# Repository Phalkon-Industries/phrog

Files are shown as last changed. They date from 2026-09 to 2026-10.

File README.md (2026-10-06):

# phrog
Super low cost spectrophotometric ph sensor

What is the purpose of the pHrog?

To be an educational kit that people can build themselves and use to learn how to make a spectrophotometric measurement.

It should be able to do basic spectrophotometric measuremtns and be able to get pH to +-0.1 units. That is the goal. 

It should be easy to build, and be repairable.

Still under early development

## Repository layout

| Folder | Contents |
|---|---|
| `phrog-mainboard/` | KiCad project, datasheets, and production outputs for the mainboard. |
| `enclosure/` | FreeCAD enclosure model. |
| `firmware/` | PlatformIO firmware for the nRF52840 Pro Micro (see `firmware/README.md`). |

## License

This project is licensed under the CERN Open Hardware Licence Version 2 - Strongly Reciprocal
(`CERN-OHL-S-2.0`). See [`LICENSE`](LICENSE) for the full text.

Source Location: https://github.com/Phalkon-Industries/phrog

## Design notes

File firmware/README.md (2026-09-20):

# phrog Firmware

PlatformIO project for the phrog pH instrument mainboard. The layout mirrors the Phoenix
firmware (`phoenix-instrument/platformio/PoenixV1-Firmware`); shared modules are copied
verbatim so they can be kept in sync.

## Hardware

- nRF52840 Pro Micro / nice!nano module (Adafruit nRF52 Arduino core, UF2 bootloader).
- NAU7802 24-bit I2C ADC for the photodiode signal.
- Thermistor divider read on the nRF52840 internal SAADC.
- Green and blue LEDs driven directly from GPIO.

Pin assignments: `docs/pin-map.md` and `include/device_setup.hpp`.

## Layout

| Path | Contents |
|---|---|
| `boards/`, `variants/` | Project-local nice!nano board definition and pin variant. |
| `include/device_setup.hpp`, `src/device_setup.cpp` | Pin map, board configs, bring-up sequence. |
| `src/main.cpp` | Production entry point (device setup + CLI). |
| `src/examples/mock_main.cpp` | Mock BLE application for phone-app development (ported). |
| `src/examples/led_blink_main.cpp` | Bench example that cycles the measurement LEDs every second. |
| `src/examples/adc_monitor_main.cpp` | Bench example: photodiode ADC codes, dark and lit, as a plain fixed-width table with a LOW/GOOD/HIGH verdict for trimpot tuning. |
| `src/examples/adc_monitor_ansi_colored_main.cpp` | The same monitor redrawn in place with a coloured verdict column, for terminals that render ANSI. |
| `lib/phoenix_common` | Shared `GUARD` macros and `PHX_*` return codes (ported verbatim). |
| `lib/ph_equations` | Spectrophotometric pH maths (ported verbatim). |
| `lib/phoenix_ble` | BLE server facade + Bluefruit backend (ported verbatim). |
| `lib/mocks` | Mock controller and BLE bridge (ported verbatim). |
| `lib/nau7802` | NAU7802 driver (implemented; internal LDO, DRDY-gated reads, offset calibration). |
| `lib/led_driver` | GPIO LED drive (implemented; NPN current sinks, active high). |
| `lib/light_readings` | Sweep helper (implemented; per-photodiode dark and lit codes, saturation flag, statistics ported from Phoenix). |
| `lib/thermistor_reader` | SAADC thermistor measurement (implemented; ratiometric divider, Steinhart-Hart from Phoenix). |
| `lib/cli` | Serial command interface (implemented: `b` baseline, `s` sample + pH, `c` live monitor, `v`, `help`). |
| `lib/phrog_settings` | Persistent per-unit settings in internal flash (implemented; LittleFS via InternalFS, versioned file, sweep count and thermistor offset). |
| `test/` | Unity suites; one per module. |
| `python/` | Host tooling: mock BLE tester and pytest suite (ported). |
| `docs/` | Style guide, TDD and git workflow, pin map. |

## Building

```powershell
pio run -e main            # production firmware
pio run -e mock_main       # mock BLE app
pio run -e led_blink -t upload   # flash the LED cycling bench example
pio run -e adc_monitor -t upload               # flash the plain photodiode ADC monitor (trimpot adjustment)
pio run -e adc_monitor_ansi_colored -t upload  # same monitor, redrawn in place with colour
pio device monitor -e adc_monitor_ansi_colored # watch it; the env passes the ANSI codes through
pio test -e main -vv       # full Unity suite on hardware
pio test -e main -vv -f *nau7802*
```

Run `pio` from this directory. See `docs/contributor-checklist.md` before starting work.

## Status

All planned modules are implemented and tested on hardware: LED drive, NAU7802 ADC, thermistor,
sweeps with statistics, the serial CLI, and flash-backed settings. BLE in the production app is
not yet wired up (the `mock_main` environment carries the ported Phoenix BLE stack).

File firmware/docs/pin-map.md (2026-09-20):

# phrog Pin Map

The phrog mainboard uses a no-name nRF52840 "Pro Micro" clone on the nice!nano footprint. Firmware
pin macros are defined in `include/device_setup.hpp`; the board variant in `variants/nice_nano/`
uses an identity map, so Arduino pin `N` is nRF GPIO `N` (`P1.13` is `32 + 13 = 45`).

Source of truth for the routing is the KiCad project in `phrog-mainboard/`. The table below was
checked against the PCB netlist.

## Header pins used by phrog

| Function | nRF pin | Arduino pin | Macro |
|---|---|---|---|
| Thermistor signal (SAADC)| P0.29 | 29 | `PIN_THERMISTOR_SIGNAL` |
| Thermistor drive | P0.02 | 2 | `PIN_THERMISTOR_DRIVE` |
| Green LED drive | P1.13 | 45 | `PIN_LED_GREEN_DRIVE` |
| Blue LED drive | P1.11 | 43 | `PIN_LED_BLUE_DRIVE` |
| NAU7802 DRDY | P1.00 | 32 | `PIN_NAU7802_DRDY` |
| I2C SCL (NAU7802) | P1.04 | 36 | `PIN_WIRE_SCL` (variant) |
| I2C SDA (NAU7802) | P1.06 | 38 | `PIN_WIRE_SDA` (variant) |

The thermistor divider is drive pin -> 10 k series resistor -> signal pin -> thermistor -> GND.
Each LED is an NPN current sink (10 k / 5.6 k base divider, 27 R emitter), GPIO active high.
The NAU7802 has blue on channel 1 (VIN1P) and green on channel 2 (VIN2P), both single-ended to
ground, with REFP tied to the internal LDO output.

## Module-internal pins

These are not on the header, and phrog does not currently use them. Their behaviour depends on
the board implementation, so `test/test_board_power` reports what it observes without failing
on the outcome. The values below are what our no-name clone did on the bench.

| Function | nRF pin | Arduino pin | Macro | Observed on our clone |
|---|---|---|---|---|
| Battery sense (SAADC) | P0.04 | 4 | `PIN_VBAT` (variant) | ~150 mV at the pin with no battery attached; divider ratio not yet confirmed. |
| Switched 3.3 V cutoff | P0.13 | 13 | `PIN_EXT_VCC_CUTOFF` (variant) | LOW switches off the module's 3.3 V output, which powers the NAU7802 and I2C pull-ups. HIGH or floating keeps it on. The nice!nano docs claim the opposite polarity. Leave it floating. |
| On-board LED (active low)| P0.15 | 15 | `LED_BUILTIN` (variant) | Blinks in `test_board_hello`. |

## Board definition

PlatformIO does not ship a nice!nano / Pro Micro board, so the project carries its own:

- `boards/nice_nano.json` — Adafruit nRF52 core, S140 v6.1.1 SoftDevice, Adafruit UF2 bootloader
  (same as the nice!nano ships with).
- `variants/nice_nano/variant.{h,cpp}` — pin map and peripheral defaults.

Both are selected from `platformio.ini` via `boards_dir`, `board = nice_nano`, and
`board_build.variants_dir`. The layout follows the community definition at
<https://github.com/ICantMakeThings/Nicenano-NRF52-Supermini-PlatformIO-Support>, kept inside
the repo instead of the global `.platformio` folder so every checkout builds the same way.

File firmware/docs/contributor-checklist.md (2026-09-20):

# phrog Firmware – Contributor Checklist

Use this checklist whenever you begin work in this repository. It captures the norms that keep firmware, host tooling, and documentation consistent.

## 1. Read the style guide
- Start with `docs/style-guide.md`. It covers naming rules (for example, store function return values in `return_code`), pointer usage, comment expectations, and formatting patterns specific to our Arduino targets.

## 2. Understand the project layout
- Firmware lives under `src/` and reusable drivers in `lib/`.
- Shared headers are in `include/`.
- Unity-based tests reside in `test/`.
- Host scripts and Python utilities live in `python/`.
- Pin mappings and board-wide constants are defined in `include/device_setup.hpp` (see `docs/pin-map.md`); reference them instead of adding literals.

## 3. Practice strict TDD
- Add or update Unity tests **before** changing behavior.
- Ensure tests fail first, then implement the fix or feature.
- Avoid removing tests unless the documented requirements change; adjust names or expectations as needed.
- When a plan is required, consult `docs/tdd-workflow.md` for the expected structure.

## 4. Use the PlatformIO flows
- Build the main firmware with `pio run -e main`.
- Run targeted Unity suites while iterating (`pio test -e main -vv -f <pattern>`).
- Run the full Unity suite (`pio test -e main -vv`) before shipping significant work.
- Always invoke `pio` commands from the repository root—avoid `cd ... && pio ...` wrappers that bypass automation.
- Run `clang-format` on every modified C++ source or header before committing.
- After firmware changes, compile the affected environments (for example, `pio run -e mock_main`) to prove they still build.

## 5. Test on real hardware
- Assume target boards are on your bench. Exercise new code on-device via PlatformIO.
- Do not introduce mocks or host-side simulators unless explicitly instructed.

## 6. Guard integrations
- Check existing modules in `include/` and `lib/` before adding new dependencies.
- Prefer extending the current drivers and helpers instead of introducing parallel implementations.

## 7. Explain the “why” in code
- Inline comments should justify non-obvious steps (for example, reset sequencing, timing delays, datasheet quirks).
- Update user-facing documentation or READMEs when visible behavior changes.

## 8. Commit cleanly
- Use merge-headline format `FW: <message>` when integrating to `main`.
- Keep topic-branch commits atomic and descriptive (see `docs/git-workflow.md` for details).
- Stage only related changes per commit and mention the validation you ran if it is not obvious.

## 9. Keep tests honest
- Never weaken or delete failing tests just to achieve a green run.
- Only modify test expectations when the documented requirements change, and explain why in your change notes.

## 10. Exercise the BLE regression suite
- Run the mock BLE workflows through pytest: `conda run -n phrog-python pytest python/tests/mock_ble/test_device_workflows.py --mock-ble -vv` so each command reports individually.
- Review `docs/mock_ble_testing.md` for option details, summary interpretation, and guidance on overriding the runner for simulation.

Keep this checklist alongside `docs/git-workflow.md`, `docs/style-guide.md`, and `docs/tdd-workflow.md` whenever you begin a new task. Together they cover process, style, testing discipline, and environment requirements.

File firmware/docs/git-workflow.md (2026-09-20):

# phrog Firmware – Git Workflow (Contributor Guide)

This document is the reference for how we manage topic branches, commits, and merges in the phrog firmware repo. Keep it handy when you start a new feature, bugfix, or refactor.

**Why we follow this workflow**

- Preserve small, atomic commits for traceability.
- Group related work behind descriptive merge commits created with `--no-ff` so the main branch tells a story.
- Stay focused by using lightweight topic branches instead of juggling parallel worktrees.
- Maintain an easy-to-scan history via `git log --first-parent` and merge boundaries.
- Align topic-branch commits with Conventional Commit structure while retaining the repository-standard `FW: …` headline for merges into `main`.

---

## Before you start a branch

1. Sync your main worktree:
   ```bash
   git fetch --all --prune
   git switch main
   git pull --ff-only
   ```
2. Decide on the branch scope and name using the patterns below.

## Branch naming

Create topic branches that reflect the type of work:

- `feat/<scope>-<short-summary>`
- `fix/<scope>-<short-summary>`
- `refactor/<scope>-<short-summary>`
- `chore/<scope>-<short-summary>`

Examples: `refactor/benchmark-timeouts`, `feat/channel-map-sweeps`.

> Keep branch names lowercase with dashes for readability. Avoid `wip/` prefixes—prefer starting a fresh branch when the direction changes.

---

## Commit messages inside the topic branch

Follow Conventional Commit headers so the history explains *what* changed without reading the diff:

```
<type>(<scope>): <imperative summary>
```

Types: `feat`, `fix`, `refactor`, `perf`, `docs`, `test`, `chore`, `build`, `ci`.

- ✅ `refactor(benchmark): isolate timing from IO`
- ❌ `update code`

Each commit should represent one logical change and include any tightly coupled tests or configuration updates.

> When you squash fixups locally, preserve the Conventional Commit header in the resulting commit.

---

## Start a topic branch

Create a branch directly in this workspace and keep all work for a change inside that branch.

1. Ensure `main` is up to date (see the previous section).
2. Create and switch to a branch in one step:
   ```bash
   git switch -c <topic-branch> main
   ```
   Example: `git switch -c fix/channel-map-timeouts main`
3. Develop on that branch, using `git add -p` for focused staging and keeping commits atomic.
4. When ready to share, push it with `git push -u origin <topic-branch>`.

---

## Keeping the branch current

- Periodically rebase onto `main` to absorb upstream fixes:
  ```bash
  git fetch --all --prune
  git rebase main
  ```
- Review the delta before merge:
  ```bash
  git range-diff origin/main...HEAD
  ```
- Run the full validation expected by the repository (see `docs/contributor-checklist.md` and `docs/tdd-workflow.md`).

---

## Merging back to `main`

1. Switch to the primary worktree and refresh `main`:
   ```bash
   git switch main
   git pull --ff-only
   ```
2. Merge with `--no-ff` so the topic branch remains visible:
   ```bash
   git merge --no-ff <topic-branch> \
     -m "FW: <concise summary of the grouped change>\n\n<bulleted summary / risks / scope>"
   ```
   - The merge commit message keeps the established `FW:` prefix while the body summarizes scope, rationale, and risks.
   - If you prefer Conventional Commit semantics, you can mention the type/scope in the body (for example, `Summary: feat(benchmark): expose timeout flags`).
3. Push `main` and any relevant tags:
   ```bash
   git push
   git push --tags # optional, when tagging a release
   ```

> Never fast-forward `main`. The merge commit is the “headline” for the grouped work.

---

## Branch lifecycle checklist

1. **Create** the topic branch with `git switch -c <topic> main`.
2. **Develop** with atomic Conventional Commit-style messages.
3. **Sync** regularly: `git fetch --all --prune && git rebase main` while on the topic branch.
4. **Self-review** with `git range-diff`, run required builds/tests, update docs.
5. **Merge** back to `main` using `git merge --no-ff <topic>` and an `FW:` merge headline.
6. **Tag** milestones when appropriate (for example, releases or major hardware validation).
7. **Delete** the topic branch after merge: `git branch -d <topic>` locally and `git push origin :<topic>` remotely.

---

## Quick reference

```bash
# Start a topic branch
git switch -c <topic> main

# Atomic commit loop
git add -p && git commit -m "refactor(benchmark): move timing helpers"

# Refresh against main
git fetch --all --prune && git rebase main

# Merge with grouped headline
git switch main && git pull --ff-only
git merge --no-ff <topic> -m "FW: consolidate benchmark timing\n\nSummary:\n- ...\n"

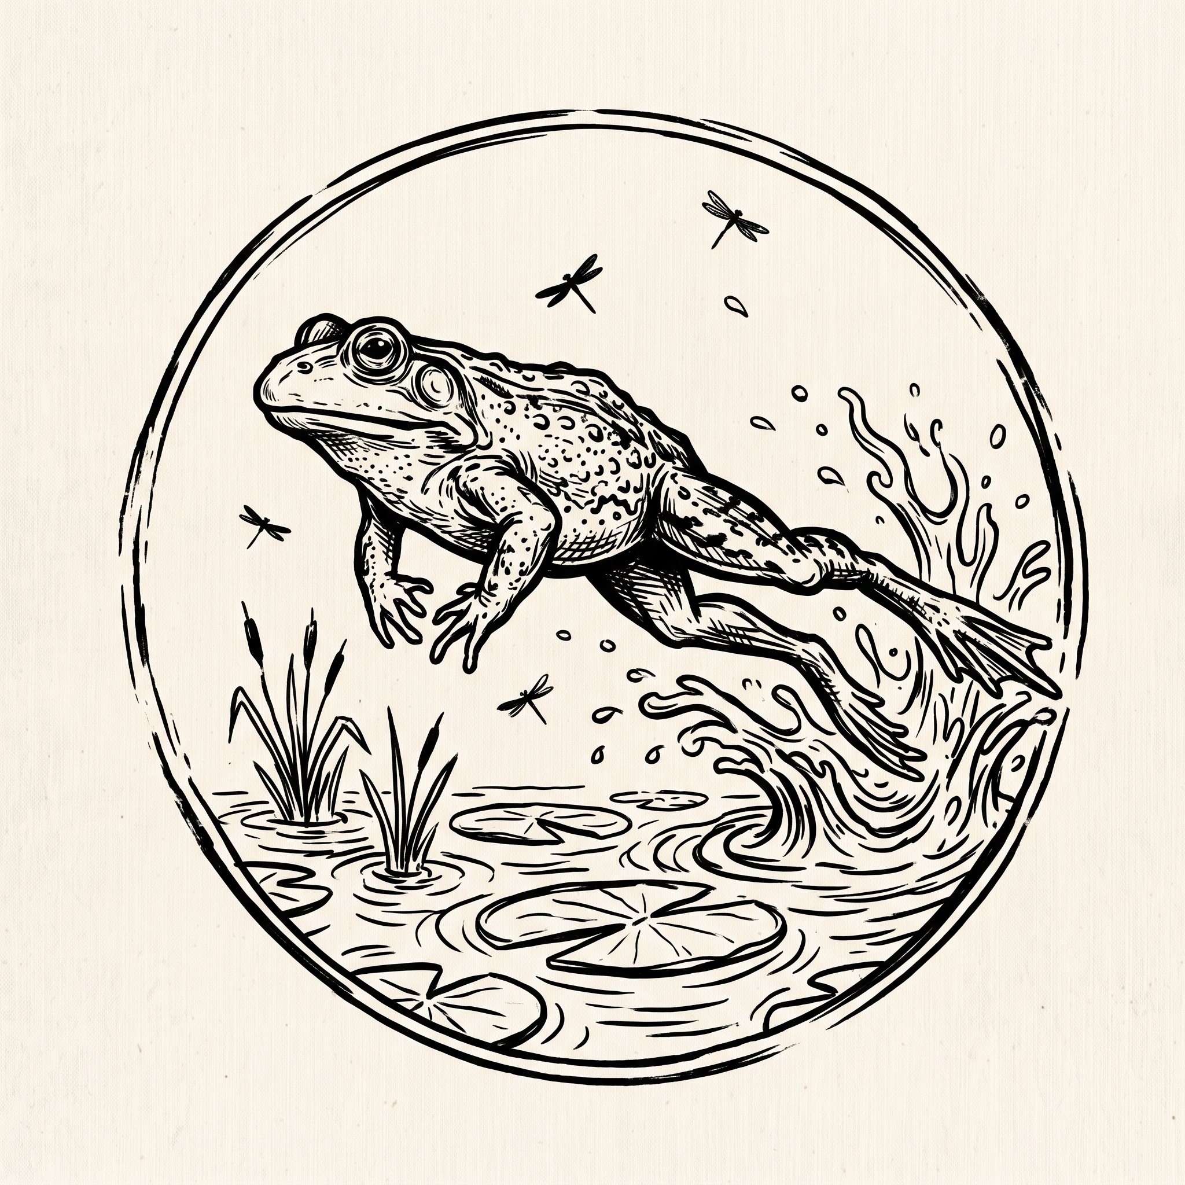
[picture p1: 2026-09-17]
phrog-mainboard/bullfrog.jpg

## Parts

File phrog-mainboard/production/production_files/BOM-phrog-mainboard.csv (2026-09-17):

Comment | Designator | Footprint | LCSC | Quantity
27R | R8 | R_Axial_DIN0207_L6.3mm_D2.5mm_P10.16mm_Horizontal |  | 1
10k | R6 | R_Axial_DIN0207_L6.3mm_D2.5mm_P10.16mm_Horizontal |  | 1
BLUELED | D3 | LED_D5.0mm_Horizontal_O1.27mm_Z3.0mm |  | 1
Photodiode | PD_Blue1 | PD_Vertical |  | 1
1N5817 | D4 | D_DO-41_SOD81_P10.16mm_Horizontal |  | 1
NRF52840 Pro Micro | U1 | nrf52840_pro_micro |  | 1
100k | RV1 | Potentiometer_Bourns_3296W_Vertical |  | 1
100nF | C2 | C_Disc_D4.3mm_W1.9mm_P5.00mm |  | 1
SW_SPDT | SW3 | SW_Slide-03_Wuerth-WS-SLTV_10x2.5x6.4_P2.54mm |  | 1
SampleThermistor | TH1 | Thermistor_Wire |  | 1
100nF | C1 | C_Disc_D4.3mm_W1.9mm_P5.00mm |  | 1
2N3904 | Q4 | TO-92_Inline |  | 1
10k | R2 | R_Axial_DIN0207_L6.3mm_D2.5mm_P10.16mm_Horizontal |  | 1
RESET | SW1 | SW_PUSH_6mm |  | 1
10uF | C5 | C_Disc_D4.3mm_W1.9mm_P5.00mm |  | 1
100nF | C6 | C_Disc_D4.3mm_W1.9mm_P5.00mm |  | 1
10k | R10 | R_Axial_DIN0207_L6.3mm_D2.5mm_P10.16mm_Horizontal |  | 1
1uF | C3 | C_Disc_D4.3mm_W1.9mm_P5.00mm |  | 1
5.6k | R13 | R_Axial_DIN0207_L6.3mm_D2.5mm_P10.16mm_Horizontal |  | 1
2N3904 | Q3 | TO-92_Inline |  | 1
27R | R9 | R_Axial_DIN0207_L6.3mm_D2.5mm_P10.16mm_Horizontal |  | 1
10k | R1 | R_Axial_DIN0207_L6.3mm_D2.5mm_P10.16mm_Horizontal |  | 1
1N5817 | D1 | D_DO-41_SOD81_P10.16mm_Horizontal |  | 1
10k | R12 | R_Axial_DIN0207_L6.3mm_D2.5mm_P10.16mm_Horizontal |  | 1
1M | RV2 | Potentiometer_Bourns_3296W_Vertical |  | 1
Battery | J1 | JST_PH_B2B-PH-K_1x02_P2.00mm_Vertical |  | 1
5.6k | R11 | R_Axial_DIN0207_L6.3mm_D2.5mm_P10.16mm_Horizontal |  | 1
7660S | U4 | DIP-8_W7.62mm_LongPads |  | 1
Photodiode | PD_Green1 | PD_Vertical |  | 1
GREENLED | D2 | LED_D5.0mm_Horizontal_O1.27mm_Z3.0mm |  | 1
LM358 | U2 | DIP-8_W7.62mm_LongPads |  | 1
10uF | C4 | C_Disc_D4.3mm_W1.9mm_P5.00mm |  | 1
NAU7802KGI | U3 | DIP-16_W7.62mm_LongPads |  | 1

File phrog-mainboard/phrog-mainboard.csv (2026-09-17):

Reference | Qty | Value | DNP | Exclude from BOM | Exclude from Board | Exclude from Simulation | Exclude from Position Files | Footprint | Datasheet
C1,C2,C6 | 3 | 100nF |  |  |  |  | ${EXCLUDE_FROM_POS_FILES} | Capacitor_THT:C_Disc_D4.3mm_W1.9mm_P5.00mm
C3 | 1 | 1uF |  |  |  |  | ${EXCLUDE_FROM_POS_FILES} | Capacitor_THT:C_Disc_D4.3mm_W1.9mm_P5.00mm
C4,C5 | 2 | 10uF |  |  |  |  | ${EXCLUDE_FROM_POS_FILES} | Capacitor_THT:C_Disc_D4.3mm_W1.9mm_P5.00mm
D1,D4 | 2 | 1N5817 |  |  |  |  | ${EXCLUDE_FROM_POS_FILES} | Diode_THT:D_DO-41_SOD81_P10.16mm_Horizontal | http://www.vishay.com/docs/88525/1n5817.pdf
D2 | 1 | GREENLED |  |  |  |  | ${EXCLUDE_FROM_POS_FILES} | LED_THT:LED_D5.0mm_Horizontal_O1.27mm_Z3.0mm
D3 | 1 | BLUELED |  |  |  |  | ${EXCLUDE_FROM_POS_FILES} | LED_THT:LED_D5.0mm_Horizontal_O1.27mm_Z3.0mm
J1 | 1 | Battery |  |  |  |  | ${EXCLUDE_FROM_POS_FILES} | Connector_JST:JST_PH_B2B-PH-K_1x02_P2.00mm_Vertical
PD_Blue1,PD_Green1 | 2 | Photodiode |  |  |  |  | ${EXCLUDE_FROM_POS_FILES} | -project:PD_Vertical
Q3,Q4 | 2 | 2N3904 |  |  |  |  | ${EXCLUDE_FROM_POS_FILES} | Package_TO_SOT_THT:TO-92_Inline | https://www.onsemi.com/pub/Collateral/2N3903-D.PDF
R1,R2,R6,R10,R12 | 5 | 10k |  |  |  |  | ${EXCLUDE_FROM_POS_FILES} | Resistor_THT:R_Axial_DIN0207_L6.3mm_D2.5mm_P10.16mm_Horizontal
R8,R9 | 2 | 27R |  |  |  |  | ${EXCLUDE_FROM_POS_FILES} | Resistor_THT:R_Axial_DIN0207_L6.3mm_D2.5mm_P10.16mm_Horizontal
R11,R13 | 2 | 5.6k |  |  |  |  | ${EXCLUDE_FROM_POS_FILES} | Resistor_THT:R_Axial_DIN0207_L6.3mm_D2.5mm_P10.16mm_Horizontal
RV1 | 1 | 100k |  |  |  |  | ${EXCLUDE_FROM_POS_FILES} | Potentiometer_THT:Potentiometer_Bourns_3296W_Vertical
RV2 | 1 | 1M |  |  |  |  | ${EXCLUDE_FROM_POS_FILES} | Potentiometer_THT:Potentiometer_Bourns_3296W_Vertical
SW1 | 1 | RESET |  |  |  |  | ${EXCLUDE_FROM_POS_FILES} | Button_Switch_THT:SW_PUSH_6mm
SW3 | 1 | SW_SPDT |  |  |  |  | ${EXCLUDE_FROM_POS_FILES} | Button_Switch_THT:SW_Slide-03_Wuerth-WS-SLTV_10x2.5x6.4_P2.54mm
TH1 | 1 | SampleThermistor |  |  |  |  | ${EXCLUDE_FROM_POS_FILES} | -project:Thermistor_Wire
U1 | 1 | NRF52840 Pro Micro |  |  |  |  | ${EXCLUDE_FROM_POS_FILES} | -project:nrf52840_pro_micro
U2 | 1 | LM358 |  |  |  |  | ${EXCLUDE_FROM_POS_FILES} | Package_DIP:DIP-8_W7.62mm_LongPads
U3 | 1 | NAU7802KGI |  |  |  |  | ${EXCLUDE_FROM_POS_FILES} | Package_DIP:DIP-16_W7.62mm_LongPads
U4 | 1 | 7660S |  |  |  |  | ${EXCLUDE_FROM_POS_FILES} | Package_DIP:DIP-8_W7.62mm_LongPads

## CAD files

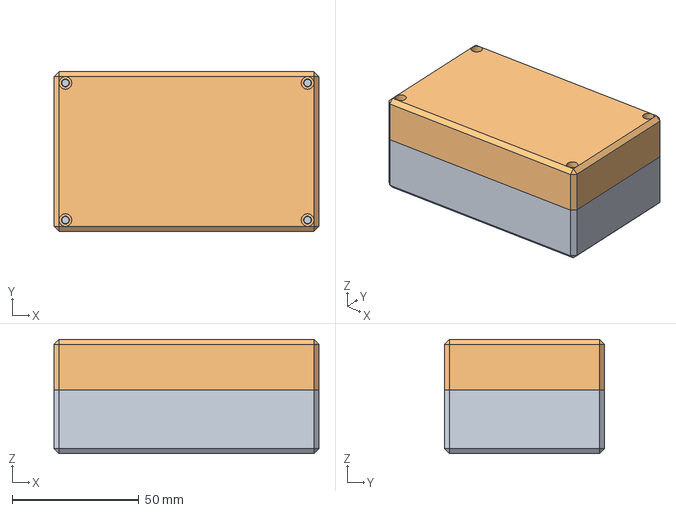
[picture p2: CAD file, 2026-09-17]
enclosure/enclosure.FCStd
104.4 x 63.0 x 45.0 mm

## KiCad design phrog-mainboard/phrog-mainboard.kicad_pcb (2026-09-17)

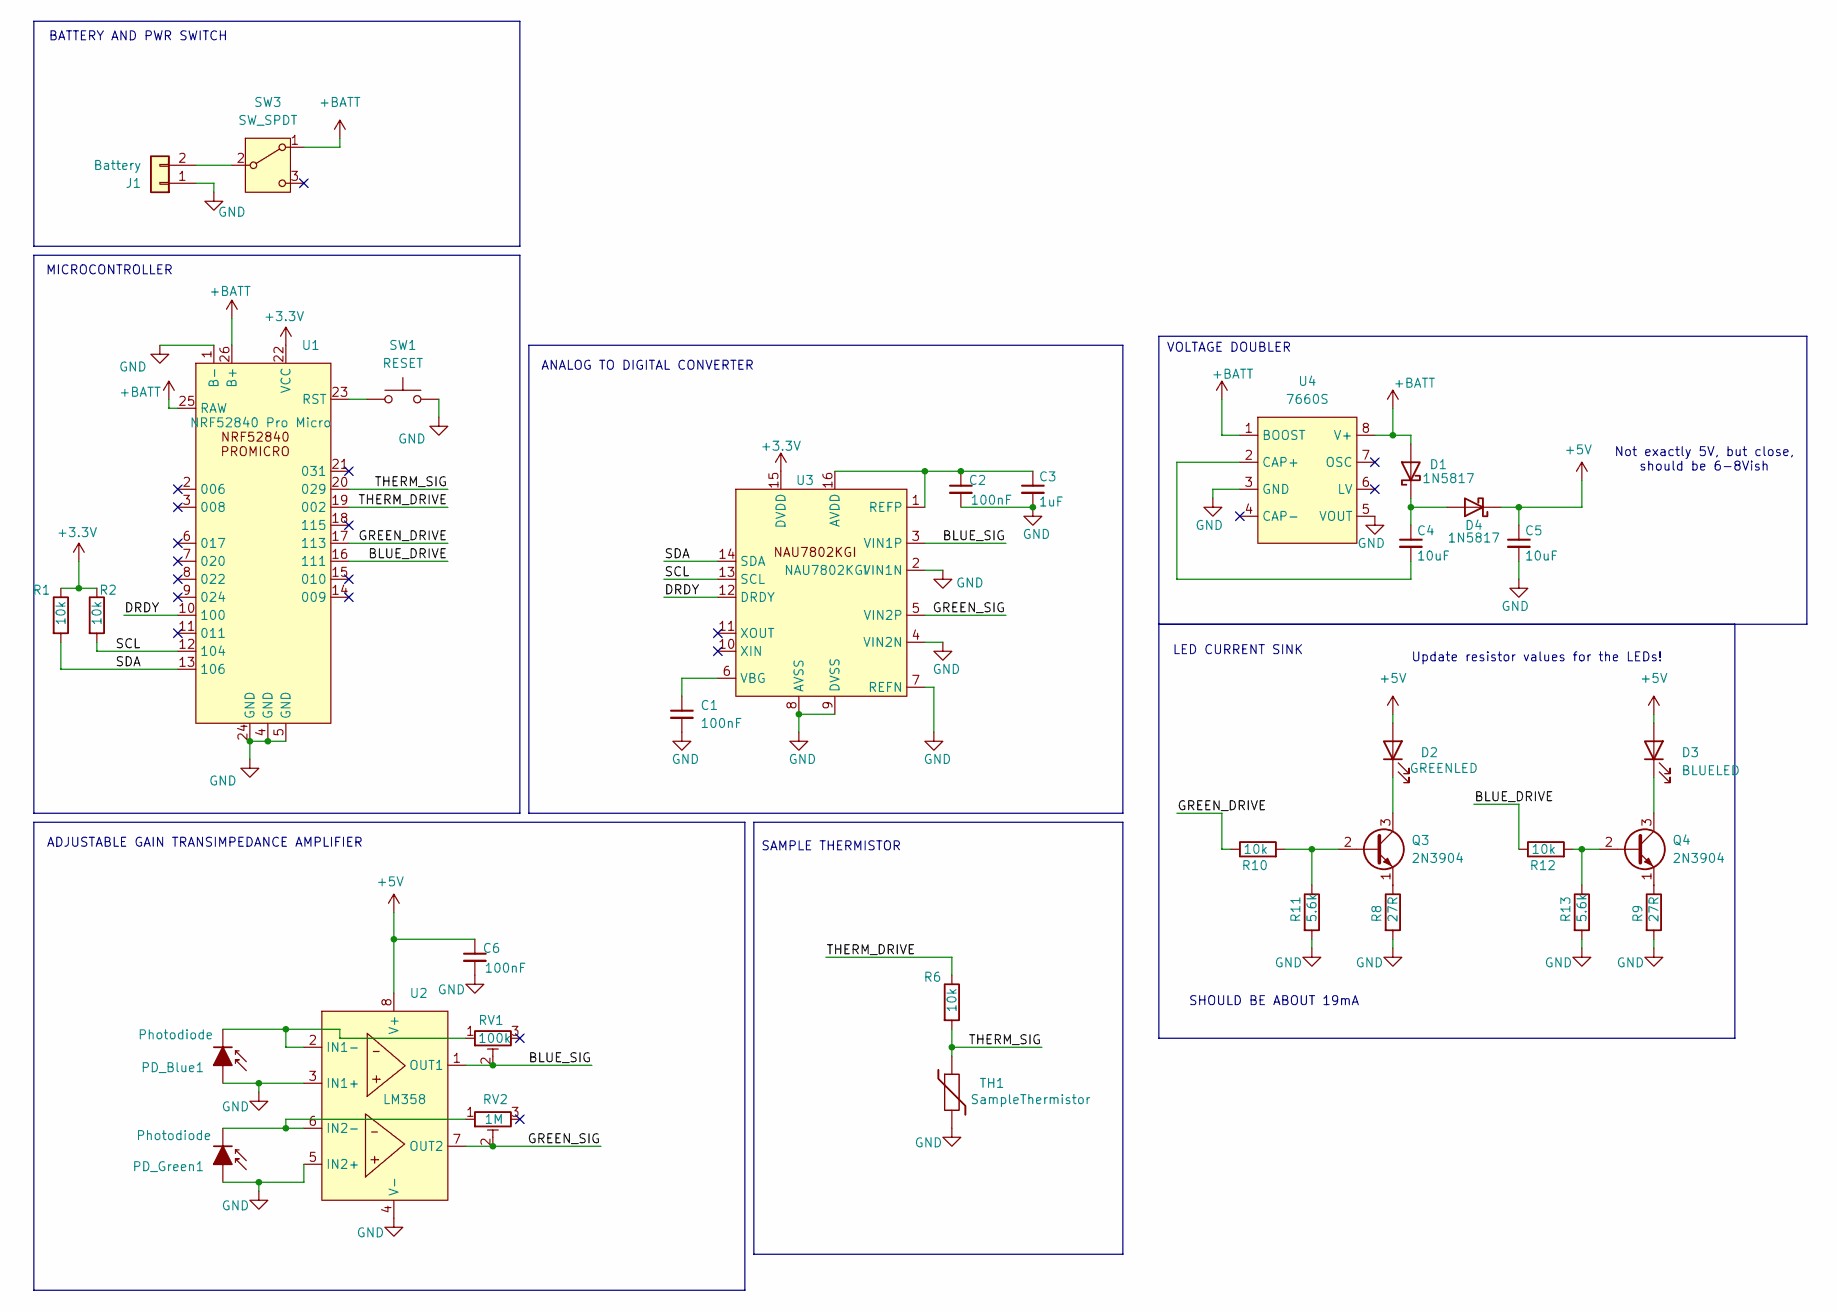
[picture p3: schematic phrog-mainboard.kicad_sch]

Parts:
C1, C2, C6: 100nF; C_Disc_D4.3mm_W1.9mm_P5.00mm
C3: 1uF; C_Disc_D4.3mm_W1.9mm_P5.00mm
C4, C5: 10uF; C_Disc_D4.3mm_W1.9mm_P5.00mm
D1, D4: 1N5817; D_DO-41_SOD81_P10.16mm_Horizontal
D2: GREENLED; LED_D5.0mm_Horizontal_O1.27mm_Z3.0mm
D3: BLUELED; LED_D5.0mm_Horizontal_O1.27mm_Z3.0mm
J1: Battery; JST_PH_B2B-PH-K_1x02_P2.00mm_Vertical
PD_Blue1: Photodiode; PD_Vertical
PD_Green1: Photodiode; PD_Vertical
Q3, Q4: 2N3904; TO-92_Inline
R1, R2, R6, R10, R12: 10k; R_Axial_DIN0207_L6.3mm_D2.5mm_P10.16mm_Horizontal
R8, R9: 27R; R_Axial_DIN0207_L6.3mm_D2.5mm_P10.16mm_Horizontal
R11, R13: 5.6k; R_Axial_DIN0207_L6.3mm_D2.5mm_P10.16mm_Horizontal
RV1: 100k; Potentiometer_Bourns_3296W_Vertical
RV2: 1M; Potentiometer_Bourns_3296W_Vertical
SW1: RESET; SW_PUSH_6mm
SW3: SW_SPDT; SW_Slide-03_Wuerth-WS-SLTV_10x2.5x6.4_P2.54mm
TH1: SampleThermistor; Thermistor_Wire
U1: NRF52840 Pro Micro; nrf52840_pro_micro
U2: LM358; DIP-8_W7.62mm_LongPads
U3: NAU7802KGI; DIP-16_W7.62mm_LongPads
U4: 7660S; DIP-8_W7.62mm_LongPads

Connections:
+3.3V: R1.1, R2.1, U1.22 (VCC), U3.15 (DVDD)
+5V: C5.1, C6.1, D2.2 (A), D3.2 (A), D4.1 (K), U2.8 (V+)
+BATT: D1.2 (A), SW3.1 (A), U1.25 (RAW), U1.26 (B+), U4.1 (BOOST), U4.8 (V+)
/BLUE_DRIVE: R12.1, U1.16 (111)
/BLUE_SIG: RV1.2, U2.1 (OUT1), U3.3 (VIN1P)
/DRDY: U1.10 (100), U3.12 (DRDY)
/GREEN_DRIVE: R10.1, U1.17 (113)
/GREEN_SIG: RV2.2, U2.7 (OUT2), U3.5 (VIN2P)
/SCL: R2.2, U1.12 (104), U3.13 (SCL)
/SDA: R1.2, U1.13 (106), U3.14 (SDA)
/THERM_DRIVE: R6.1, U1.19 (002)
/THERM_SIG: R6.2, TH1.1, U1.20 (029)
GND: C1.2, C2.2, C3.2, C5.2, C6.2, J1.1, PD_Blue1.2 (A), PD_Green1.2 (A), R8.2, R9.2, R11.2, R13.2, SW1.2, TH1.2, U1.1 (B-), U1.4 (GND), U1.5 (GND), U1.24 (GND), U2.3 (IN1+), U2.4 (V-), U2.5 (IN2+), U3.2 (VIN1N), U3.4 (VIN2N), U3.7 (REFN), U3.8 (AVSS), U3.9 (DVSS), U4.3 (GND), U4.5 (VOUT)
unnamed: C4.1, D1.1 (K), D4.2 (A)
unnamed: D2.1 (K), Q3.3 (C)
unnamed: D3.1 (K), Q4.3 (C)
unnamed: J1.2, SW3.2 (B)
unnamed: PD_Blue1.1 (K), RV1.1, U2.2 (IN1-)
unnamed: PD_Green1.1 (K), RV2.1, U2.6 (IN2-)
unnamed: Q3.2 (B), R10.2, R11.1
unnamed: Q3.1 (E), R8.1
unnamed: Q4.2 (B), R12.2, R13.1
unnamed: Q4.1 (E), R9.1
unnamed: SW1.1, U1.23 (RST)
unnamed: C2.1, C3.1, U3.1 (REFP), U3.16 (AVDD)
unnamed: C1.1, U3.6 (VBG)
unnamed: C4.2, U4.2 (CAP+)

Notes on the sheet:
Not exactly 5V, but close, should be 6-8Vish
SHOULD BE ABOUT 19mA
VOLTAGE DOUBLER
LED CURRENT SINK
SAMPLE THERMISTOR
BATTERY AND PWR SWITCH
ADJUSTABLE GAIN TRANSIMPEDANCE AMPLIFIER
MICROCONTROLLER
Update resistor values for the LEDs!
ANALOG TO DIGITAL CONVERTER

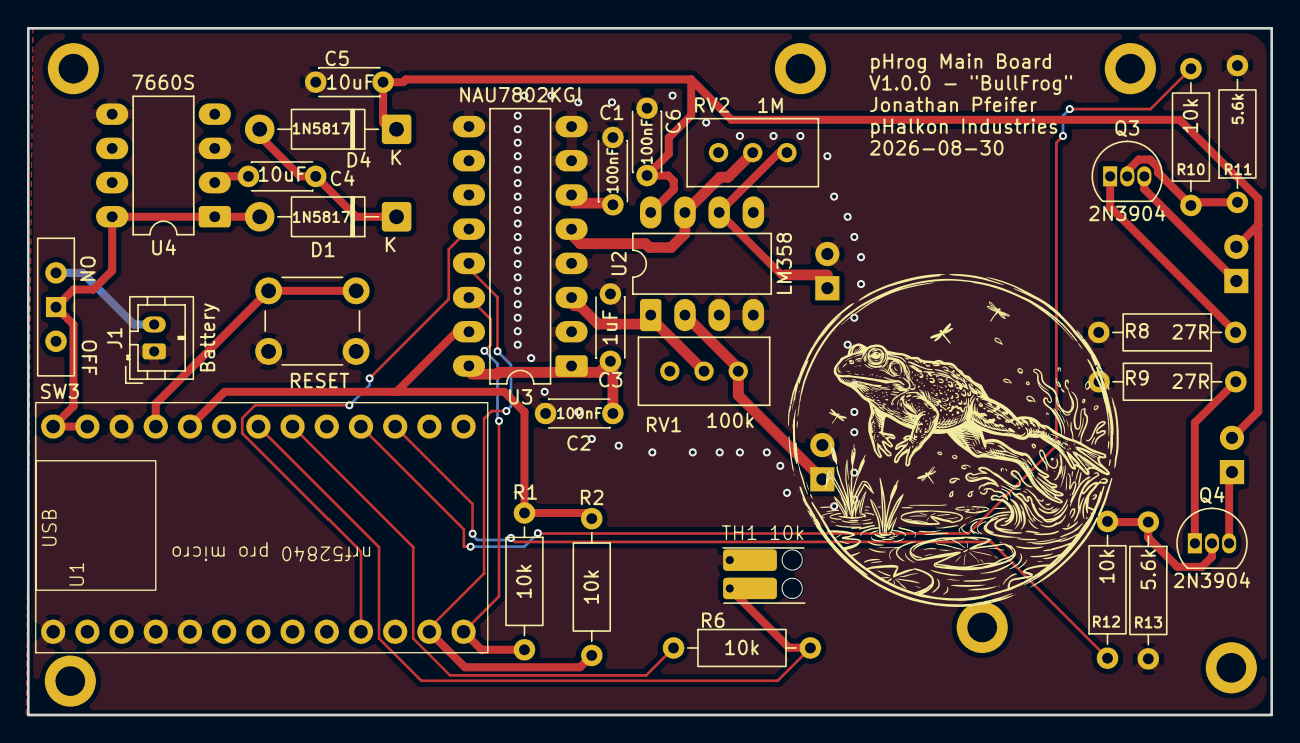
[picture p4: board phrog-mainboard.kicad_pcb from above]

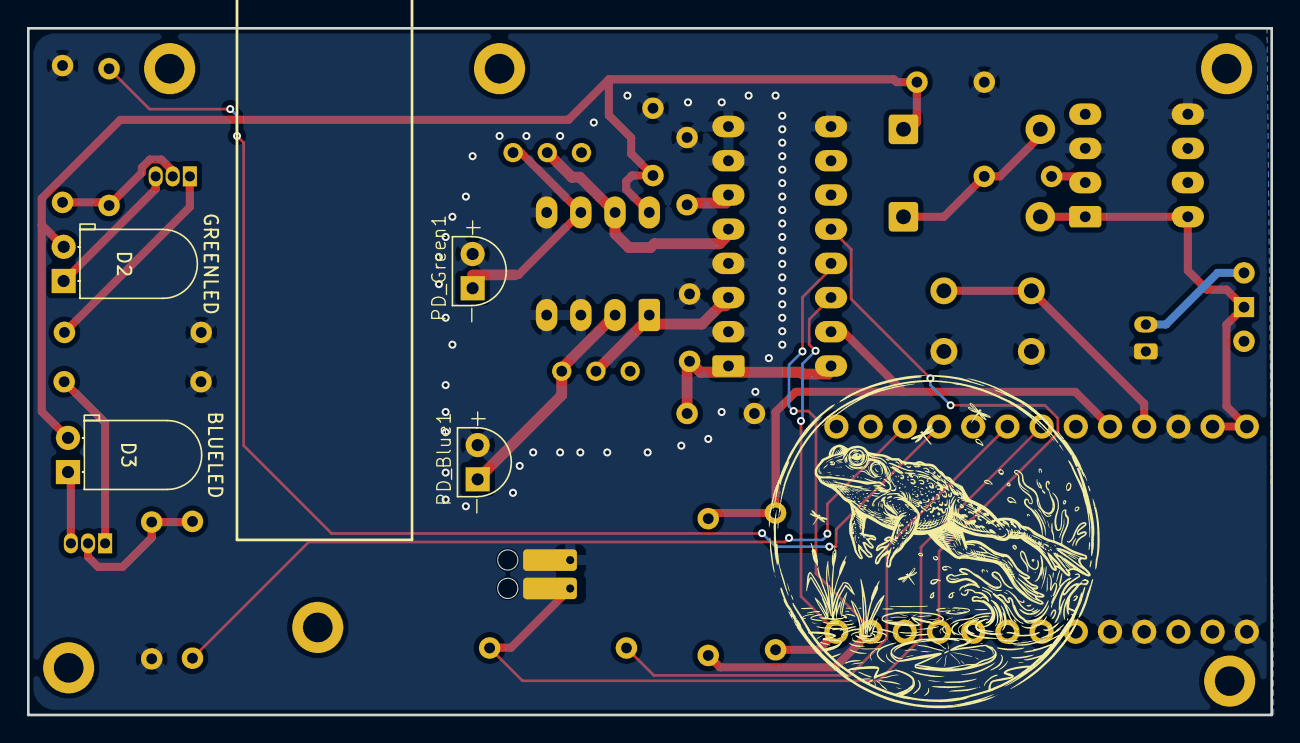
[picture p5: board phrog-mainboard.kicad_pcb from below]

Board: 2 copper layers, 92.4 x 51.0 mm, 33 parts (4 on the bottom side), 27 nets.

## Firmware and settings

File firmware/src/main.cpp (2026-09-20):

#ifndef PIO_UNIT_TESTING  // Allows device_setup.cpp to be shared with tests via test_build_src.

#include "cli.hpp"
#include "device_setup.hpp"
#include <Arduino.h>

#ifndef PHROG_STARTUP_WARMUP_DELAY_MS
#define PHROG_STARTUP_WARMUP_DELAY_MS 0u
#endif

#ifndef PHROG_DEVICE_SETUP_RETRY_DELAY_MS
#define PHROG_DEVICE_SETUP_RETRY_DELAY_MS 500u
#endif

#ifndef PHROG_DEVICE_SETUP_RETRY_LIMIT
#define PHROG_DEVICE_SETUP_RETRY_LIMIT 0u
#endif

void setup() {
  // Step 1: Open the USB serial link before anything can report an error.
  Serial.begin(115200);
  delay(100);  // Short delay to allow serial to set up.

  // Step 2: Configure the instrument before accepting CLI commands.
  uint32_t setup_attempt_count = 0u;
  while (true) {
    const int return_code = device_setup_initialize();
    if (return_code == PHX_OK) {
      break;
    }

    Serial.print("error\tdevice_setup_initialize\t");
    Serial.println(return_code);

    ++setup_attempt_count;
    if ((PHROG_DEVICE_SETUP_RETRY_LIMIT > 0u) && (setup_attempt_count >= PHROG_DEVICE_SETUP_RETRY_LIMIT)) {
      return;
    }

    delay(PHROG_DEVICE_SETUP_RETRY_DELAY_MS);
  }

  // Step 3: Optionally allow LEDs and sensors to warm up before measurements.
  if (PHROG_STARTUP_WARMUP_DELAY_MS > 0u) {
    delay(PHROG_STARTUP_WARMUP_DELAY_MS);
  }

  // Step 4: Bring up the CLI so baseline/sample commands can be received.
  cli_initialize();
}

void loop() {
  // Step 1: Service CLI commands.
  cli_poll();
}

#endif

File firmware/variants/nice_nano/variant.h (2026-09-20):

/*
  nice!nano v2 / nRF52840 "Pro Micro" (SuperMini) variant for the Adafruit nRF52 Arduino core.

  Pin numbering is an identity map: Arduino pin N is nRF52840 GPIO N, where N = port * 32 + pin.
  So P0.29 is pin 29 and P1.13 is pin 32 + 13 = 45. This mirrors the community definition at
  https://github.com/ICantMakeThings/Nicenano-NRF52-Supermini-PlatformIO-Support and keeps the
  firmware pin macros readable against the schematic's Pxx.yy labels.

  Derived from the Adafruit Feather nRF52840 Express variant (LGPL-2.1; see the Adafruit core).
*/

#ifndef _VARIANT_NICE_NANO_
#define _VARIANT_NICE_NANO_

/** Master clock frequency */
#define VARIANT_MCK (64000000ul)

#define USE_LFXO  // nice!nano and SuperMini clones fit a 32.768 kHz crystal.

/*----------------------------------------------------------------------------
 *        Headers
 *----------------------------------------------------------------------------*/

#include "WVariant.h"

#ifdef __cplusplus
extern "C" {
#endif  // __cplusplus

// Number of pins defined in the g_ADigitalPinMap array (see variant.cpp).
#define PINS_COUNT (48)
#define NUM_DIGITAL_PINS (48)
#define NUM_ANALOG_INPUTS (8)  // P0.02..P0.05 and P0.28..P0.31 (AIN0..AIN7).
#define NUM_ANALOG_OUTPUTS (0)

// Port 0 GPIO (Arduino pin == nRF pin).
#define PIN_P0_02 (2)
#define PIN_P0_03 (3)
#define PIN_P0_04 (4)
#define PIN_P0_05 (5)
#define PIN_P0_06 (6)
#define PIN_P0_07 (7)
#define PIN_P0_08 (8)
#define PIN_P0_09 (9)
#define PIN_P0_10 (10)
#define PIN_P0_11 (11)
#define PIN_P0_12 (12)
#define PIN_P0_13 (13)
#define PIN_P0_14 (14)
#define PIN_P0_15 (15)
#define PIN_P0_16 (16)
#define PIN_P0_17 (17)
#define PIN_P0_18 (18)
#define PIN_P0_19 (19)
#define PIN_P0_20 (20)
#define PIN_P0_21 (21)
#define PIN_P0_22 (22)
#define PIN_P0_23 (23)
#define PIN_P0_24 (24)
#define PIN_P0_25 (25)
#define PIN_P0_26 (26)
#define PIN_P0_27 (27)
#define PIN_P0_28 (28)
#define PIN_P0_29 (29)
#define PIN_P0_30 (30)
#define PIN_P0_31 (31)

// Port 1 GPIO (Arduino pin == 32 + nRF pin).
#define PIN_P1_00 (32)
#define PIN_P1_01 (33)
#define PIN_P1_02 (34)
#define PIN_P1_03 (35)
#define PIN_P1_04 (36)
#define PIN_P1_05 (37)
#define PIN_P1_06 (38)
#define PIN_P1_07 (39)
#define PIN_P1_08 (40)
#define PIN_P1_09 (41)
#define PIN_P1_10 (42)
#define PIN_P1_11 (43)
#define PIN_P1_12 (44)
#define PIN_P1_13 (45)
#define PIN_P1_14 (46)
#define PIN_P1_15 (47)

// LEDs: the single on-board blue LED sits on P0.15 and is active low on the nice!nano.
// Bluefruit requires LED_BLUE / LED_CONN to exist even when unused.
#define PIN_LED1 PIN_P0_15
#define LED_BUILTIN PIN_LED1
#define LED_CONN PIN_LED1
#define LED_RED PIN_LED1
#define LED_BLUE PIN_LED1
#define LED_STATE_ON 0  // State when LED is lit (active low).

/*
 * Analog pins (SAADC inputs AIN0..AIN7).
 */
#define PIN_A0 PIN_P0_02
#define PIN_A1 PIN_P0_03
#define PIN_A2 PIN_P0_04
#define PIN_A3 PIN_P0_05
#define PIN_A4 PIN_P0_28
#define PIN_A5 PIN_P0_29
#define PIN_A6 PIN_P0_30
#define PIN_A7 PIN_P0_31

static const uint8_t A0 = PIN_A0;
static const uint8_t A1 = PIN_A1;
static const uint8_t A2 = PIN_A2;
static const uint8_t A3 = PIN_A3;
static const uint8_t A4 = PIN_A4;
static const uint8_t A5 = PIN_A5;
static const uint8_t A6 = PIN_A6;
static const uint8_t A7 = PIN_A7;
#define ADC_RESOLUTION 14

// Battery sense and switched-rail control. These are internal to the module (not on the header).
// Their behaviour depends on the board implementation: the nice!nano documentation, the community
// variant, and the no-name clone phrog uses all disagree. phrog does not currently use either pin;
// test/test_board_power reports what a given board does so nobody has to trust the documentation.
#define PIN_VBAT PIN_P0_04  // Battery divider sense (AIN2). Read ~150 mV with no battery on our clone.
// On our clone, driving P0.13 LOW switches off the module's 3.3 V output pin, which on phrog powers
// the NAU7802 and the I2C pull-ups; HIGH or floating (the power-on state) keeps the rail up. The
// nice!nano documentation claims the opposite polarity. Leave the pin floating.
#define PIN_EXT_VCC_CUTOFF PIN_P0_13

/*
 * Serial interfaces (Pro Micro RX/TX pads).
 */
#define PIN_SERIAL1_RX PIN_P0_08
#define PIN_SERIAL1_TX PIN_P0_06

/*
 * SPI Interfaces. The core requires a definition; phrog does not use SPI, so these sit on
 * otherwise-unused pads.
 */
#define SPI_INTERFACES_COUNT 1

#define PIN_SPI_MISO PIN_P1_15
#define PIN_SPI_MOSI PIN_P1_02
#define PIN_SPI_SCK PIN_P1_01

static const uint8_t SS   = PIN_P1_07;
static const uint8_t MOSI = PIN_SPI_MOSI;
static const uint8_t MISO = PIN_SPI_MISO;
static const uint8_t SCK  = PIN_SPI_SCK;

/*
 * Wire Interfaces. phrog routes the NAU7802 on P1.04 (SCL) / P1.06 (SDA) per docs/pin-map.md.
 */
#define WIRE_INTERFACES_COUNT 1

#define PIN_WIRE_SDA PIN_P1_06
#define PIN_WIRE_SCL PIN_P1_04

// No QSPI flash on the module; leave EXTERNAL_FLASH_* undefined so the core skips it.

#ifdef __cplusplus
}
#endif

#endif  // _VARIANT_NICE_NANO_

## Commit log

2026-08-24 Get most of schematic finished
    [phrog-mainboard.kicad_pcb, phrog-mainboard.kicad_sch]
2026-08-25 start routing PCB
    [phrog-mainboard.kicad_pcb]
2026-09-17 finish first draft of enclosure
    [BOM-phrog-mainboard.csv, enclosure.FCStd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]
2026-09-20 Add a basic board test to make sure board is working
2026-09-20 Add tests for onboard pins for battery level and vcc output
2026-09-20 FW: Implement LED Driver stuff
2026-09-20 FW: Add thermistor reader code
2026-09-20 FW: Create adc montior for calibrating gain
2026-10-06 Build a bench logger to test warmup drift
    [drift_logger_main.cpp]
